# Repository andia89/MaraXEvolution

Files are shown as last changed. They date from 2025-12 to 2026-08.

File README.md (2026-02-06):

# MaraX Evolution - Main Controller




### Screenshot
[](https://github.com/user-attachments/assets/aa3f5071-2165-40e5-ae51-54051c40426c)

### Videos
| [](https://github.com/user-attachments/assets/e88c7372-fec7-41ba-ae10-4c3a202e55e9) | [](https://github.com/user-attachments/assets/11aead3c-08d9-41a0-b3eb-2458ce605d03) |
|:--:| :--:|
| *Pressure profiling with a blind flange. The pressure follows a complicated profile* | *Real shot with the custom Controller. The profile is set to produce a flat 9bar shot that stops at 40g (since the valve is not closed by the lever there will always be some additional coffee coming out after the pump stopped). As one can see the pressure neatly follows the 9bar (at one point I adjusted with the flow control paddle so that is when the pressure dropped). The grind was way to fine for this shot :D* |

This repository contains the hardware design and firmware for the **MaraX Evolution** main controller board. This project is designed to replace the stock controller of the Lelit Mara X espresso machine, adding advanced features such as PID temperature control, pressure profiling, weighing scale integration, and WiFi connectivity.

## Features

### Core Control
* **Hybrid Thermal Control:** Utilizes a custom **Feed-Forward + PID algorithm** (`feedForwardHeater`) that estimates heat loss based on ambient vs. boiler temperature, offering better stability than standard PIDs.
* **Dual-PID Architecture:** Dedicated PID loops for Temperature (Boiler/HX) and Pump (Pressure/Flow).
* **Smart State Machine:** Manages states including `COOLING_FLUSH`, `STEAM_BOOST`, and `STANDBY`.
* Performs all tasks the original Lelit MaraX machine does as well (boiler refill, water tank presence detection, relay activations etc...)

### Profiling & Extraction
* **Pressure Profiling:** Real-time pump dimmer control via Zero-Cross detection.
* **Flow Profiling:** (Requires [MaraX Evolution Scale](https://github.com/andia89/MaraXEvolution-Scale/)) Target specific flow rates (g/s) using Kalman-filtered weight data.
* **Gravimetric stopping:** (Requires [MaraX Evolution Scale](https://github.com/andia89/MaraXEvolution-Scale/)) Stop the shot after a set amount of time or when a certain weight is reached
* **Advanced Profiles:** Supports manual control, flat 9-bar shots, or complex JSON-based profiles (Ramped or Stepped).

### Integration & Connectivity
* **WiFi & MQTT:** Full smart home integration. Reports sensors (`boiler_temp`, `pressure`, `weight`) and accepts commands remotely.
* **Telnet CLI:** Built-in command-line interface for debugging and calibration over WiFi.
* **ESP-NOW HMI:** Low-latency connection to the optional [MaraX Evolution HMI](https://github.com/andia89/maraxevolution-hmi).
* **OTA Updates:** Update firmware wirelessly without opening the machine.

### Maintenance
* **Automated Cleaning:** Built-in backflush program (`CLEANING_START` -> `CLEANING_PUMPING` -> `PAUSE`).
* **Scale Calibration:** Integrated wizard for taring and calibrating the load cell.

## Repository Structure

* `controller_board/`: KiCad v6 hardware design files (schematics, PCB layout, and fabrication files).
* `firmware/`: PlatformIO project source code for the ESP32-based controller.

## Hardware Assembly

1.  **PCB Fabrication:** Use the Gerber and Drill files provided in `controller_board/jlcpcb/production_files/` to order the PCB.
2.  **Assembly:** Solder the components according to the BOM (`BOM-controller_board.csv`). The board features an Arduino-Nano ESP32 compatible footprint. See [Assembly](ASSEMBLY.md) for details
3.  **Installation:** Replace the existing Mara X controller with this board, ensuring all connections (sensors, pump, heating element) are mapped correctly.

## Firmware Compilation

The firmware is modular. You can enable/disable hardware features via `platformio.ini` build flags:

```cpp
build_flags = 
    -D HAS_PRESSURE_GAUGE
    -D HAS_SCALE
    -D HAS_SCREEN
```

The firmware is built using **PlatformIO**.

1.  Install [VSCode](https://code.visualstudio.com/) and the [PlatformIO extension](https://platformio.org/).
2.  Clone this repository.
3.  Open the `firmware` folder in PlatformIO.
4.  Configure `platformio.ini` if necessary (e.g., to select specific build environments or upload ports)
5.  Click the **Build** icon (checkmark) to compile.
6.  Connect your Arduino Nano ESP32 board via USB and click **Upload** (select `env:firmware` build environment).
7.  For subsequent uploads OTA should be enabled (you might have to adjust IP-address in `platformio.ini`) and selecting the `env:firmware-ota` environment

## [User Guide](USERGUIDE.md)

## [Parts list](PARTS.md)

## [Assembly instructions](ASSEMBLY.md)

## Support me

I had way too much fun building the MaraX Evolution—it turned into quite the obsession! I am definitely planning to tackle another coffee machine and give it the same "Evolution" treatment.

**However, espresso machines are expensive! :D**

If you enjoy this project or use it daily, please consider supporting me.

**Your Support = Your Vote**

When you support me on Ko-fi or Patreon, **please leave a comment telling me which coffee machine you want me to do next.**

Think of it as a voting system: As soon as I have enough funds to cover the machine with the most votes (and the parts to mod it), I will buy it, reverse-engineer it, and build an open-source controller for it. If you have the MaraX and still want to support me, you can also tell me if there is a specific feature you want to have!

I will keep track of the money earned and will update occasionally the votes on the different coffee machines that are requested

## Limitations
* The MaraX is a very good heatexchanger machine, using quite sophisticated hardware to achieve superior temperature stability than a lot of other HX machines out of the box. It is, however, not a dual boiler machine and as such perfect temperature control is almost impossible. I played around a lot with PID values and was able to come up with some good values (and some pretty sophisticated feed forward control), but still perfect stability is almost impossible (or only if one tunes the PID super conservative, but then it takes hours to heat the machine)
* This is not a cheap project. Most parts can be sourced pretty cheaply, but I used good ADC chips (the ADS1115) and one unfortunately obsolete LM1830 chip for boiler water level detection as well as a pretty expensive power supply for the 12V power. Most of these things could certainly be done cheaper (and maybe someday will). All in all expect to spend a bit of money if you go for the full set (which is recommended).
* In the end the softweare got waaaaay more complicated than I originally anticipated. Some software was written using AI but I went through all of it and made sure it made sense to me. There certainly will be bugs as there is an infinite amount of edge cases I certainly have not considered. Please report any bugs you may find

## Disclaimer & Safety Warning

**PLEASE READ CAREFULLY BEFORE PROCEEDING.**

**1. I am a Hobbyist, Not a Professional**
I am **not** a professional mechanical, electrical, or software engineer. This project was created purely as a personal hobby undertaking for educational purposes. The code and hardware designs provided here are **not** certified, tested to industrial standards, or guaranteed to be bug-free.

**2. Warranty Voiding**
Modifying your espresso machine, uploading custom firmware, or opening the chassis **will almost certainly void your manufacturer’s warranty**. By proceeding with any instructions or files from this repository, you accept full responsibility for the loss of any existing warranty or support from the original manufacturer.

**3. No Liability**
This software and hardware documentation is provided **"AS IS", WITHOUT WARRANTY OF ANY KIND**, express or implied.
* **I am not responsible** for any damage to your machine (bricking the device, burning out components, leaks, etc.).
* **I am not responsible** for any personal injury or property damage (including fire or electrical shock) resulting from the use of this project.
* **You assume all risk** associated with modifying your hardware and running this software.

**4. High Voltage & Pressure Warning**
Espresso machines involve **Mains Electricity (110V/220V)**, **Water**, and **High Pressure**. This is a dangerous combination.
* Never work on the machine while it is plugged in.
* Ensure you have a proper understanding of electrical safety before attempting any hardware modifications.
* Improper handling of the boiler or pressure lines can result in explosion or severe burns.

**Use this project entirely at your own risk.**

If you find anything that you think could be improved (be it software/electrical or mechanical side) please let me know, and feel free to open a Pull request

## Licensing
This project is dual-licensed to protect the work while allowing for personal study and modification.

* **Firmware:** The main source code located in the `/firmware` directory is licensed under the **PolyForm Noncommercial License 1.0.0**. You may modify and use it for personal projects, but you cannot use it for commercial products.
    * *Third-Party Libraries:* This firmware includes modified versions of the following libraries, which remain under their original licenses:
        * [dimmable-light](https://github.com/fabianoriccardi/dimmable-light): Licensed under **LGPL-2.1**.
        * [PID_v1](https://github.com/br3ttb/Arduino-PID-Library/tree/master): Licensed under **MIT License**.
        * [Simple Kalman Filter](https://github.com/denyssene/SimpleKalmanFilter): Licensed under **MIT License**.

* **Firmware:** The hardware designs, schematics, and 3D models located in the /controller_board and /hv_board directories are licensed under the Creative Commons Attribution-NonCommercial 4.0 International (CC BY-NC 4.0) license.

Please see the LICENSE file in each respective subdirectory for the full legal text.

## Similar projects
Idea for controlling the pump via an AC dimmer has been done in https://github.com/larszi/marax-pressure-mod. A complete overhaul of control software is currently proposed by the great project in https://github.com/variegated-coffee (they try to make a one-fit all solution though)

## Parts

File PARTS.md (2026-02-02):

## Parts List

 * PCBs for both the controller board and the HV board. I had good experience with JLCPCB but PCBWay is also fine. The gerber files can be found in production_files in the jlcpcb folder. 

* Electronic parts for assembly. They are listed at the end of this section in [Controller board](#conroller-board) and [HV board](#hv-board)

* If you want to use a pressure transducer (this is necessary to do profiling based on pressure, and to electronically monitor the pressure). 
    * The board is designed for [this one](https://aliexpress.com/item/4000756631924.html?spm=a2g0o.order_list.order_list_main.5.ee9e1802cAHCQO); specifically 0-1.6MPa at 0.5V-4.5V and a supply voltage of 12V
    * [T-Piece for pipe](https://www.landefeld.de/artikel/de/t-steckanschluss-5mm-5mm-iqs-msv-standard-/IQST%2050%20MSV). It is important to note that the MaraX uses 5mm pipes which are quite non-standard
    * [Pipe push fitting](https://www.landefeld.de/artikel/de/steckanschluss-m-innengew-m-5-4mm-iqs-msv-standard-/IQSF%20M54%20MSV)
    * [5mm polyurethane pipe](https://www.landefeld.de/artikel/de/polyurethan-schlauch-5-x-3-mm-blau-meterware-von-50-mtr-rolle-/PU%205X3%20BLAU); get 1m to have a bit left-over
    * [Molex connector](https://www.mouser.at/ProductDetail/Molex/50-57-9403?qs=u6Gr9%2FNt%252B%2F9Ok3bHhq8UPA%3D%3D) that has its mate on the controller board, with at least [3 Receptables that need to be crimped on the wire](https://www.mouser.at/ProductDetail/Molex/16-02-0102?qs=UAyrm%2FnZ%252BCifWkt7bqgfPw%3D%3D)
* If you want to use AC dimmer for flow/pressure profiling (and you either have the Pressure transducer and/or the scale installed) one additional (ideally heat-resistant cable) is necessary. Two [Connectors](https://www.mouser.at/ProductDetail/571-606501) like this one have to be crimped on a sufficiently long cable. 

### Controller Board

The BOM for the controller board is divided into **SMD components** (suitable for JLCPCB's SMT service) and **Handsolder components** (precision parts, connectors, and the microcontroller to be sourced from Mouser/DigiKey).

#### 1. SMD Components (JLCPCB SMT Service)
These components have LCSC part numbers included in the BOM and can be assembled by the JLCPCB SMT service. Alternatively they can be of course hand soldered. These Resistors and Capacitors are mainly used for Pull-up/down, current limiting and filtering, as such their exact values are not that important. The transistors are mainly used for switching LEDs. In both controller_board and hv_board folder there is a jlcpcb folder that contains all the necessary files for fabrication as well as SMT assembly.

| Comment | Designator | Footprint | LCSC Part | Qty |
| :--- | :--- | :--- | :--- | :--- |
| **0** | R15 | R 0805 | [C17477](https://lcsc.com/product-detail/C17477.html) | 1 |
| **0.05uF** | C6 | C 0805 | [C53134](https://lcsc.com/product-detail/C53134.html) | 1 |
| **0.22u** | C3 | C 0805 | [C5378](https://lcsc.com/product-detail/C5378.html) | 1 |
| **100nF** | C7, C8, C9, C11 | C 0805 | [C28233](https://lcsc.com/product-detail/C28233.html) | 4 |
| **1nF** | C4 | C 0805 | [C46653](https://lcsc.com/product-detail/C46653.html) | 1 |
| **1uF** | C1, C2, C5, C10 | C 0805 | [C28323](https://lcsc.com/product-detail/C28323.html) | 4 |
| **10K** | R1, R3, R5, R7, R9, R10, **R13**, R18, R20, R22, R24, R28, R30, R31, R32, R33, R35, R38 | R 0805 | [C17414](https://lcsc.com/product-detail/C17414.html) | 18 |
| **20uF** | C13 | C 0805 | [C45783](https://lcsc.com/product-detail/C45783.html) | 1 |
| **47uF** | C12 | C 0805 | [C28323](https://lcsc.com/product-detail/C28323.html) | 1 |
| **220** | R23, R25, R26, R34, R36, R39 | R 0805 | [C17557](https://lcsc.com/product-detail/C17557.html) | 6 |
| **300** | R8 | R 0805 | [C17617](https://lcsc.com/product-detail/C17617.html) | 1 |
| **30K** | R17, R19, R21 | R 0805 | [C17621](https://lcsc.com/product-detail/C17621.html) | 3 |
| **470** | R14, R27, R37, R40 | R 0805 | [C17710](https://lcsc.com/product-detail/C17710.html) | 4 |
| **47K** | R6, R29 | R 0805 | [C17713](https://lcsc.com/product-detail/C17713.html) | 2 |
| **BSS138** | Q1, Q2, Q3, Q4, Q5, Q6 | SOT-23 | [C15277](https://lcsc.com/product-detail/C15277.html) | 6 |

#### 2. Handsolder Components (Mouser / DigiKey)
These parts are not included in the SMT assembly and must be purchased separately.

**Precision Resistors**
*0.1% tolerance is recommended for these voltage dividers. If this is really necessary I am not sure, but I used 0.1% tolerance ones and it works great*

| Value | Designator | Qty | Link (Mouser) |
| :--- | :--- | :--- | :--- |
| **1K5** | R12 | 1 | [0805 1.5K 0.1%](https://www.mouser.com/c/?q=0805%20resistor%201.5kOhms%200.1%25) |
| **5K6** | R11 | 1 | [0805 5.6K 0.1%](https://www.mouser.com/c/?q=0805%20resistor%205.6kOhms%200.1%25) |
| **10K** | R2, R4 | 2 | [0805 10K 0.1%](https://www.mouser.com/c/?q=0805%20resistor%2010kOhms%200.1%25) |
| **-** | **R16** | **0** | **DNP (Do Not Populate)** |

**ICs & Modules**

| Part Name | Designator | Description | Qty | Link (Mouser) | Comment | 
| :--- | :--- | :--- | :--- | :--- | :--- |
| **Arduino Nano ESP32**| A1 | Microcontroller | 1 | [Arduino Nano ESP32](https://www.mouser.com/c/?q=Arduino%20Nano%20ESP32) | with headers if directly soldered to the board. Otherwise [Mill-Max](https://www.mill-max.com/products/new/precision-machined-pin-headers) headers are a way to socket it (there is not enough vertical space for standard machine headers)
| **ADS1115IDGS** | U1 | 16-Bit ADC | 1 | [ADS1115IDGS](https://www.mouser.com/c/?q=ADS1115IDGS) | Any ADS1115 will work fine
| **AQV212** | IC1 | PhotoMOS Relay | 1 | [AQV212](https://www.mouser.com/c/?q=AQV212%20DIP-6) | can be socketed using standard DIP-6 socket
| **IE092503-1** | U3 | Buzzer | 1 | [IE092503-1](https://www.mouser.com/c/?q=IE092503-1) | If you don't want a buzzer, can be omitted
| **LM4050AEM3-3.0** | IC2 | Voltage Reference 3.0V | 1 | [LM4050AEM3-3.0](https://www.mouser.com/c/?q=LM4050AEM3-3.0) | A precise voltage reference for temperature measurements

**Connectors**

| Part Name | Designator | Description | Qty | Link (Mouser) | Comment | 
| :--- | :--- | :--- | :--- | :--- | :--- |
| **280377-2** | CN1, CN2, CN3, CN4, CN5, CN7 | TE Ampmodu II (2 pos) | 6 | [TE 280377-2](https://www.mouser.com/c/?q=280377-2) |
| **280389-2** | CN6 | TE Ampmodu II (8 pos) | 1 | [TE 280389-2](https://www.mouser.com/c/?q=280389-2) |
| **70553-0002** | J4 | Molex SL Header (3 pos)| 1 | [Molex 70553-0002](https://www.mouser.com/c/?q=705530002) | Can be omitted if no pressure transducer is to be installed
| **70553-0041** | J5 | Molex SL Header (7 pos) | 1 | [Molex 70553-0041](https://www.mouser.com/c/?q=705530041) | Can be omitted if no scale is to be installed
| **MTMM-106-14-T-S-520** | J2 | 2.00mm Pitch Header | 1 | [Header 1x06 2mm](https://www.mouser.com/c/?q=MTMM-106-14-T-S-520) | This mates with the correspnding ESQT connector on the HV board. The exact part numbers are not that important, but the two connectors need to bridge a gap of 27mm (distance between the topsides of both PCBs)

#### 3. Special Components
This component is obsolete and typically requires sourcing from eBay.

| Component | Designator | Note | Link | Comment |
| :--- | :--- | :--- | :--- | :--- |
| **LM1830N** | U2 | Fluid Level Detector | [Search on eBay](https://www.ebay.com/sch/i.html?_nkw=LM1830N) | Can be socketed by using socket for N14A package

### HV Board

These components have LCSC part numbers included in the BOM and can be assembled by the JLCPCB SMT service. Alternatively they can be of course hand soldered. These Resistors and Capacitors are mainly used for Pull-up/down, current limiting and filtering, as such their exact values are not that important. Transistors are used to switch the Relays and Diodes as flyback. Both can be cheaply done with SMT service from JLCPCB

#### 1. SMD Components (JLCPCB SMT Service)
These components have LCSC part numbers and can be assembled by the JLCPCB SMT service.

| Comment | Designator | Footprint | LCSC Part | Qty |
| :--- | :--- | :--- | :--- | :--- |
| **100** | R8 | R 0805 | [C17408](https://lcsc.com/product-detail/C17408.html) | 1 |
| **10K** | R1, R28 | R 0805 | [C17414](https://lcsc.com/product-detail/C17414.html) | 2 |
| **1k** | R7 | R 0805 | [C17513](https://lcsc.com/product-detail/C17513.html) | 1 |
| **BAT46WJ** <br>*(I would have liked the BAT46WJ but only the BAT46WS is available for SMT service. It is also fine)* | U3, U4 | SC-90 / SOD323F | [C7502692](https://lcsc.com/product-detail/C7502692.html) | 2 |
| **BSS138** | Q1, Q2 | SOT-23 | [C7420339](https://lcsc.com/product-detail/C7420339.html) | 2 |

#### 2. Handsolder Components (Mouser / DigiKey)
These parts involve mains voltage or high power.

**High Power Resistors (2010 Package)**
*Note: These require the larger 2010 [5025 metric] footprint for power handling. Go for Power rating of >1W for those*

| Value | Designator | Qty | Link (Mouser) | Comments |
| :--- | :--- | :--- | :--- | :--- |
| **47k** | R5, R6 | 2 | [2010 Resistor 47k](https://www.mouser.com/c/?q=2010%20resistor%2047k) | Use at least 1W rating. Can be omitted if AC dimmer is not used
| **330** | R9 | 1 | [2010 Resistor 330](https://www.mouser.com/c/?q=2010%20resistor%20330) | Use at least 1W rating. Can be omitted if AC dimmer is not used
| **39** | R11 | 1 | [2010 Resistor 39](https://www.mouser.com/c/?q=2010%20resistor%2039) | Use at least 1W rating. Can be omitted if AC dimmer is not used

**Relays, Triacs & Power Modules**

| Part Name | Designator | Description | Qty | Link (Mouser) | Comment |
| :--- | :--- | :--- | :--- | :--- | :--- |
| **ECE10US12** | U1 | AC-DC Converter 12V | 1 | [ECE10US12](https://www.mouser.com/c/?q=ECE10US12) |
| **ALDP112** | U2 | Panasonic Relay 12V | 1 | [ALDP112](https://www.mouser.com/c/?q=ALDP112) |
| **RT314A12** | K1 | TE Schrack Relay 12V | 1 | [RT314A12](https://www.mouser.com/c/?q=RT314A12) |
| **BTA16-600BWRG**| Q3 | Triac 600V 16A | 1 | [BTA16-600BWRG](https://www.mouser.com/c/?q=BTA16-600BWRG) | Can be omitted if AC dimmer is not used
| **H11L1** | U5 | Optocoupler (Logic) | 1 | [H11L1](https://www.mouser.com/c/?q=H11L1) | Can be omitted if AC dimmer is not used. Can be socketed with DIP-6 socket
| **MOC3021M** | U7 | Optocoupler (Triac) | 1 | [MOC3021M](https://www.mouser.com/c/?q=MOC3021M) | Can be omitted if AC dimmer is not used. Can be socketed with DIP-6 socket
| **W04G** | D1 | Bridge Rectifier | 1 | [W04G](https://www.mouser.com/c/?q=W04G) | Can be omitted if AC dimmer is not used
| **7178DG** | H1 | Heatsink for Triac | 1 | [7178DG](https://www.mouser.com/c/?q=7178DG) | Can be omitted if AC dimmer is not used

**Capacitors & Fuses**

| Part Name | Designator | Description | Qty | Link (Mouser) | Comment |
| :--- | :--- | :--- | :--- | :--- | :--- |
| **VJ2220Y103K...**| C1 | 2220 Safety Cap X2 | 1 | [VJ2220Y103KXUSTX2](https://www.mouser.com/c/?q=VJ2220Y103KXUSTX2) | Can be omitted if AC dimmer is not used
| **100uF** | C3 | Radial (D6.3mm P2.5mm) | 1 | [100uF Radial 6.3mm 2.5mm](https://www.mouser.com/c/?q=100uF%20radial%206.3mm%202.5mm%20pitch) |
| **0034.6808** | F1 | Schurter MSS Fuse | 1 | [0034.6808](https://www.mouser.com/c/?q=0034.6808) |
| **0697H9100-02** | F2 | Bel Fuse Radial | 1 | [0697H9100-02](https://www.mouser.com/c/?q=0697H9100-02) |
| **3413.0215.22** | F4 | Schurter SMD Fuse | 1 | [3413.0215.22](https://www.mouser.com/c/?q=3413.0215.22) |

**Connectors**

| Name | Designator | Description | Qty | Link |
| :--- | :--- | :--- | :--- | :--- |
| **571-160650-2** | FA1, FA4, FA7, FA10, FA11 | Faston Tabs 6.35mm | 5 | [571-160650-2](https://www.mouser.at/ProductDetail/571-160650-2) |
| **ESQT-106-02-L-S-530** | J6 | 2.00mm Pitch Female Header Receptable | 1 | [Socket 1x06 2mm](https://www.mouser.com/c/?q=ESQT-106-02-L-S-530) | This mates with the corresponding MTMM connector on the controller board. The exact part numbers are not that important, but the two connectors need to bridge a gap of 27mm (distance between the topsides of both PCBs)

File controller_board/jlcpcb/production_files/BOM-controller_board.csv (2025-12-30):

Comment | Designator | Footprint | LCSC | Quantity
0 | R15 | R_0805_2012Metric_Pad1.20x1.40mm_HandSolder | C17477 | 1
0.05uF | C6 | C_0805_2012Metric_Pad1.18x1.45mm_HandSolder | C53134 | 1
0.22u | C3 | C_0805_2012Metric_Pad1.18x1.45mm_HandSolder | C5378 | 1
100nF | C11,C7,C8,C9 | C_0805_2012Metric_Pad1.18x1.45mm_HandSolder | C28233 | 4
10K | R1,R10,R13,R18,R20,R22,R24,R28,R3,R30,R31,R32,R33,R35,R38,R5,R7,R9 | R_0805_2012Metric_Pad1.20x1.40mm_HandSolder | C17414 | 18
1nF | C4 | C_0805_2012Metric_Pad1.18x1.45mm_HandSolder | C46653 | 1
1uF | C1,C10,C2,C5 | C_0805_2012Metric_Pad1.18x1.45mm_HandSolder | C28323 | 4
20uF | C13 | C_0805_2012Metric_Pad1.18x1.45mm_HandSolder | C45783 | 1
220 | R23,R25,R26,R34,R36,R39 | R_0805_2012Metric_Pad1.20x1.40mm_HandSolder | C17557 | 6
300 | R8 | R_0805_2012Metric_Pad1.20x1.40mm_HandSolder | C17617 | 1
30K | R17,R19,R21 | R_0805_2012Metric_Pad1.20x1.40mm_HandSolder | C17621 | 3
470 | R14,R27,R37,R40 | R_0805_2012Metric_Pad1.20x1.40mm_HandSolder | C17710 | 4
47K | R29,R6 | R_0805_2012Metric_Pad1.20x1.40mm_HandSolder | C17713 | 2
47uF | C12 | C_0805_2012Metric_Pad1.18x1.45mm_HandSolder | C16780 | 1
BSS138 | Q1,Q2,Q3,Q4 | SOT-23 | C7420339 | 4
5K6 | R11 | R_0805_2012Metric_Pad1.20x1.40mm_HandSolder |  | 1
Heater SSR Relay | CN5 | 280377-2_TYC |  | 1
1K5 | R12 | R_0805_2012Metric_Pad1.20x1.40mm_HandSolder |  | 1
LM1830N | U2 | PDIP14_19P56X6P35_ONS |  | 1
705530041 | J5 | CONN_70553-xxxx_07_MOL |  | 1
MISC LEDS | CN6 | 280389-2_TYC |  | 1
HV Board | J2 | PinHeader_1x06_P2.00mm_Vertical |  | 1
Brew switch | CN7 | 280377-2_TYC |  | 1
AQV212 | IC1 | DIP762W47P254L880H410Q6N |  | 1
IE092503-1 | U3 | IE0925031 |  | 1
Sensor brew boiler | CN4 | 280377-2_TYC |  | 1
10K | R2 | R_0805_2012Metric_Pad1.20x1.40mm_HandSolder |  | 1
705530002 | J4 | CONN_705530002_03_MOL |  | 1
LM4050AEM3-3.0+T | IC2 | SOT95P237X112-3N |  | 1
1-100k | R16 | R_0805_2012Metric_Pad1.20x1.40mm_HandSolder |  | 1
Water level detector | CN2 | 280377-2_TYC |  | 1
ADS1115IDGS | U1 | VSSOP-10_3x3mm_P0.5mm |  | 1
Boiler fill sensor | CN1 | 280377-2_TYC |  | 1
10K | R4 | R_0805_2012Metric_Pad1.20x1.40mm_HandSolder |  | 1
Arduino_Nano_ESP32 | A1 | Arduino_Nano |  | 1
Sensor steam boiler | CN3 | 280377-2_TYC |  | 1

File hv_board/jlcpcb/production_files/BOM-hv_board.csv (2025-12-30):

Comment | Designator | Footprint | LCSC | Quantity
100 | R8 | R_0805_2012Metric_Pad1.20x1.40mm_HandSolder | C17408 | 1
10K | R1,R28 | R_0805_2012Metric_Pad1.20x1.40mm_HandSolder | C17414 | 2
1k | R7 | R_0805_2012Metric_Pad1.20x1.40mm_HandSolder | C17513 | 1
BAT46WJ_115 | U3,U4 | SC-90_SOD323F_NEX | C7502692 | 2
BSS138 | Q1,Q2 | SOT-23 | C7420339 | 2
ALDP112 | U2 | PAN_ALD_PAN |  | 1
H11L1 | U5 | H11L1_ISO |  | 1
47k | R6 | R_2010_5025Metric_Pad1.40x2.65mm_HandSolder |  | 1
0034.6808 | F1 | FUS_SCHURTER_0034_SCH |  | 1
W04G | D1 | Diode_Bridge_Round_D9.8mm |  | 1
47k | R5 | R_2010_5025Metric_Pad1.40x2.65mm_HandSolder |  | 1
7178DG | H1 | 7178DG |  | 1
MOC3021M | U7 | PDIP6_BX_ONS |  | 1
230 Live | FA1 | 1606502 |  | 1
VJ2220Y103KXUSTX2 | C1 | CAPC5651X218N |  | 1
Pump Relay | FA11 | 1606502 |  | 1
39 | R11 | R_2010_5025Metric_Pad1.40x2.65mm_HandSolder |  | 1
RT314A12 | K1 | Relay_SPDT_Schrack-RT1-16A-FormC_RM5mm |  | 1
3413.0215.22 | F4 | FUS1206_24N_SCH |  | 1
230 Neutral | FA4 | 1606502 |  | 1
BTA16-600BWRG | Q3 | TO255P460X1020X2005-3P |  | 1
PumpOut | FA10 | 1606502 |  | 1
100uF | C3 | CP_Radial_D6.3mm_P2.50mm |  | 1
330 | R9 | R_2010_5025Metric_Pad1.40x2.65mm_HandSolder |  | 1
Coffee Relay | FA7 | 1606502 |  | 1
ECE10US12 | U1 | RELAY4_ECE10_XPR |  | 1
0697H9100-02 | F2 | 0697_BEL |  | 1
Controller board | J6 | PinHeader_1x06_P2.00mm_Vertical |  | 1

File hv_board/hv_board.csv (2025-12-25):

ID | Bezeichner | Footprint | Stückzahl | Bezeichnung | Anbieter und Referenz
1 | U2 | PAN_ALD_PAN | 1 | ALDP112
2 | U5 | H11L1_ISO | 1 | H11L1
3 | R6,R5 | R_2010_5025Metric_Pad1.40x2.65mm_HandSolder | 2 | 47k
4 | F1 | FUS_SCHURTER_0034_SCH | 1 | 0034.6808
5 | D1 | Diode_Bridge_Round_D9.8mm | 1 | W04G
6 | R1,R28 | R_0805_2012Metric_Pad1.20x1.40mm_HandSolder | 2 | 10K
7 | H1 | 7178DG | 1 | 7178DG
8 | U7 | PDIP6_BX_ONS | 1 | MOC3021M
9 | FA1 | 1606502 | 1 | 230 Live
10 | FA11 | 1606502 | 1 | Pump Relay
11 | U3,U4 | SC-90_SOD323F_NEX | 2 | BAT46WJ_115
12 | R11 | R_2010_5025Metric_Pad1.40x2.65mm_HandSolder | 1 | 39
13 | K1 | Relay_SPDT_Schrack-RT1-16A-FormC_RM5mm | 1 | RT314A12
14 | R7 | R_0805_2012Metric_Pad1.20x1.40mm_HandSolder | 1 | 1k
15 | Q1,Q2 | SOT-23 | 2 | BSS138
16 | F4 | FUS1206_24N_SCH | 1 | 3413.0215.22
17 | R8 | R_1206_3216Metric_Pad1.30x1.75mm_HandSolder | 1 | 86.6
18 | FA4 | 1606502 | 1 | 230 Neutral
19 | Q3 | TO255P460X1020X2005-3P | 1 | BTA16-600BWRG
20 | C2 | CAP_F339MX231031MDA2B0_VIS | 1 | F339MX231031MDA2B0
21 | FA10 | 1606502 | 1 | PumpOut
22 | C3 | CP_Radial_D6.3mm_P2.50mm | 1 | 100uF
23 | R9 | R_2010_5025Metric_Pad1.40x2.65mm_HandSolder | 1 | 330
24 | FA7 | 1606502 | 1 | Coffee Relay
25 | U1 | RELAY4_ECE10_XPR | 1 | ECE10US12
26 | F2 | 0697_BEL | 1 | 0697H9100-02
27 | J6 | PinHeader_1x06_P2.00mm_Vertical | 1 | Controller board

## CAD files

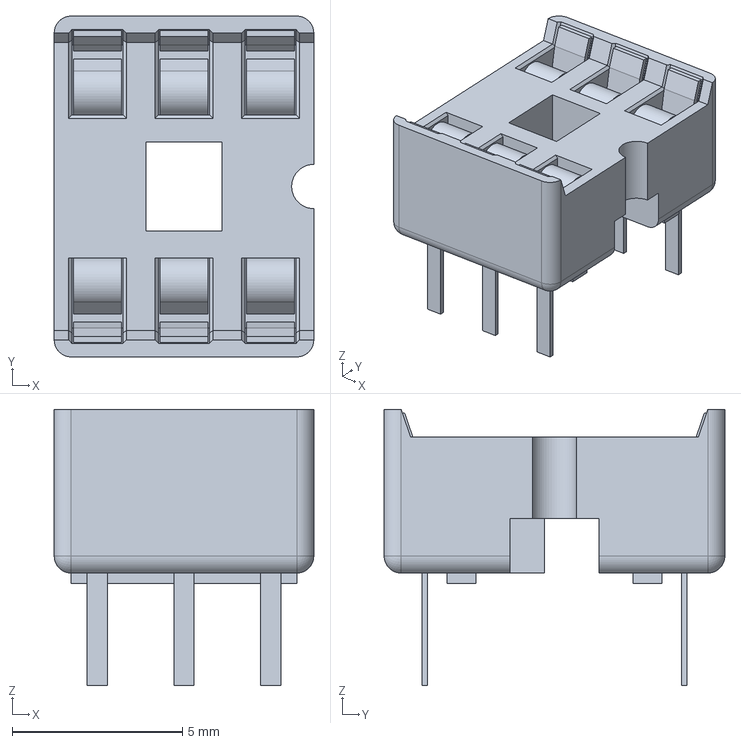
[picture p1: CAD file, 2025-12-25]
controller_board/LIB_1-2199298-1/1-2199298-1/3D/1-2199298-1.stp
7.62 x 10.0 x 8.10 mm

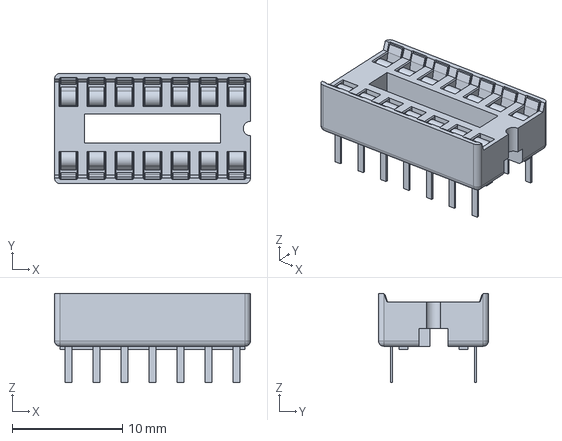
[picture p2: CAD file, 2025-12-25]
controller_board/LIB_1-2199298-3/1-2199298-3/3D/1-2199298-3.stp
17.8 x 10.0 x 8.10 mm

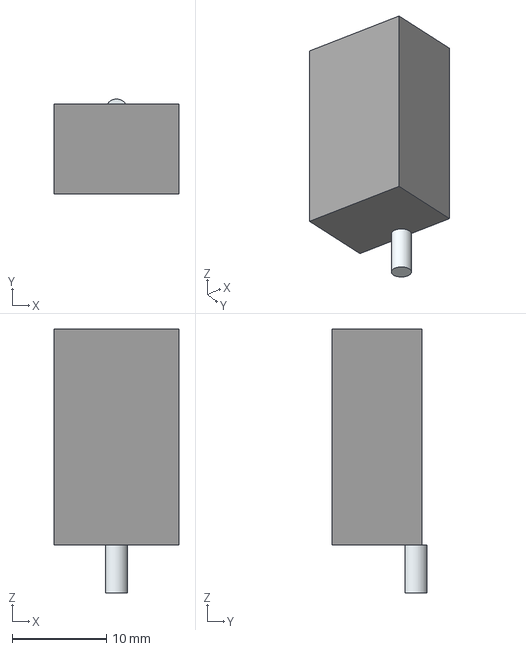
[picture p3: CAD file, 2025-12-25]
controller_board/LIB_7178DG/7178DG/3D/7178DG.stp
13.2 x 10.1 x 28.0 mm
Leads

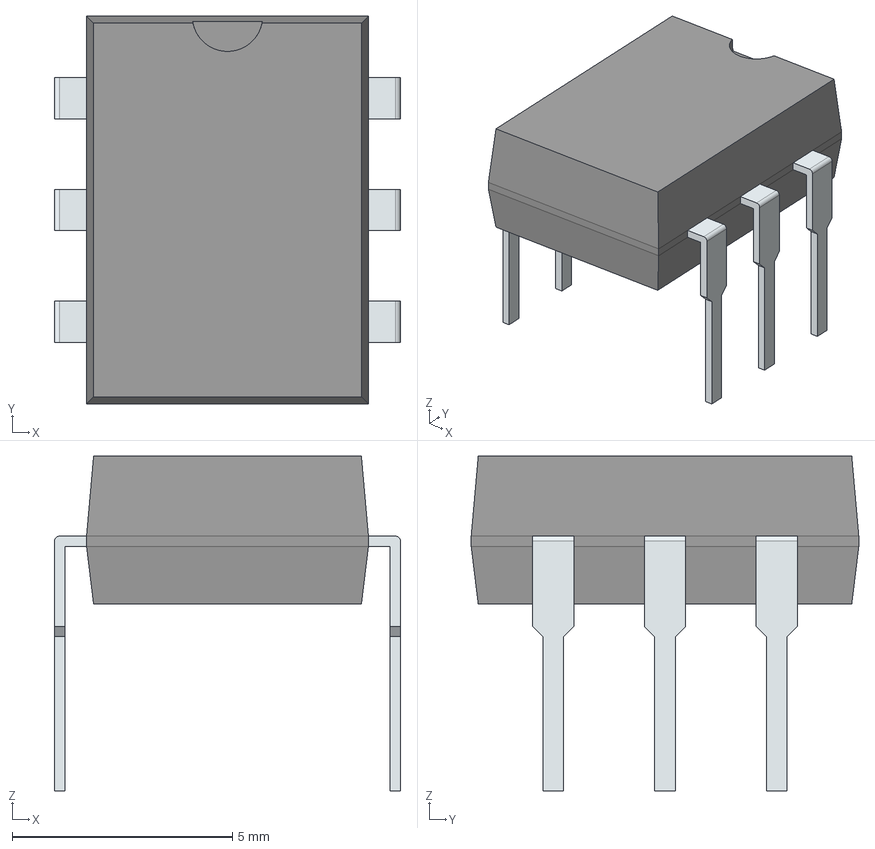
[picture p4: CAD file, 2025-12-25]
controller_board/LIB_AQV212/AQV212/3D/AQV212.stp
7.86 x 8.80 x 7.60 mm
PinsArrayLR

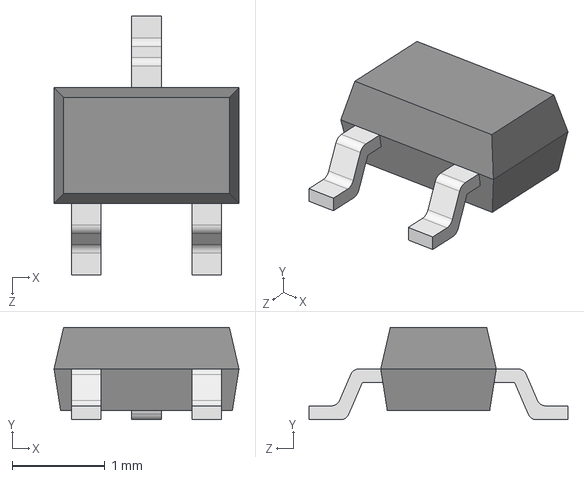
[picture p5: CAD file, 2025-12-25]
controller_board/LIB_LM4050AEM3-3.0+T/LM4050AEM3-3.0+T/3D/LM4050AEM3-3.0+T.stp
2.00 x 1.00 x 2.80 mm

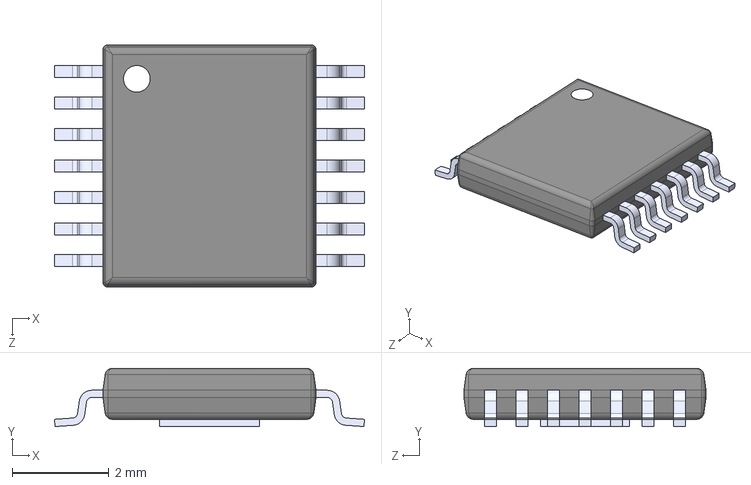
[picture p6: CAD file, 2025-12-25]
controller_board/LIB_TPS1HTC30AQPWPRQ1/TPS1HTC30AQPWPRQ1/3D/TPS1HTC30AQPWPRQ1.stp
6.40 x 1.20 x 5.00 mm

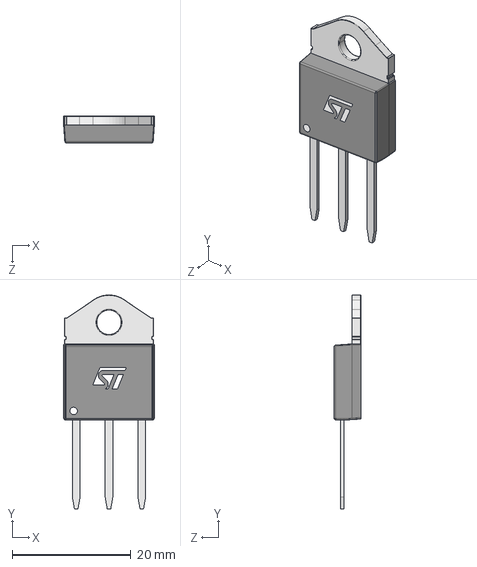
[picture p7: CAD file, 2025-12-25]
hv_board/LIB_BTA16-600BWRG/BTA16-600BWRG/3D/BTA16-600BWRG.stp
15.3 x 36.1 x 4.50 mm
T5035H-8PI
STMicro Logo

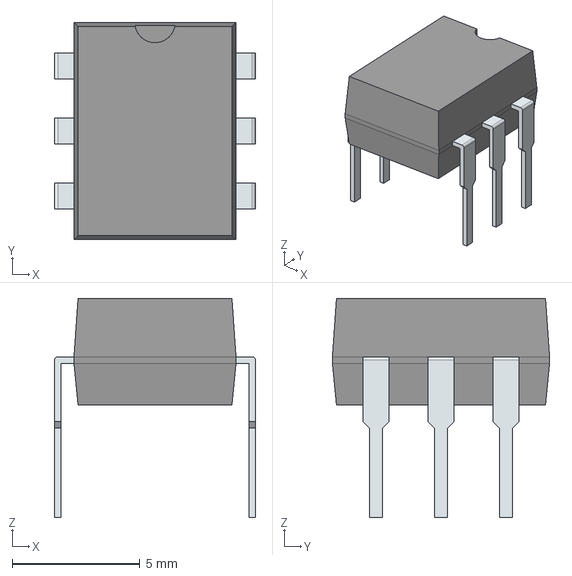
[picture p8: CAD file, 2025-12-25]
hv_board/LIB_H11L1M/H11L1M/3D/H11L1M.stp
7.88 x 8.51 x 8.58 mm
PinsArrayLR

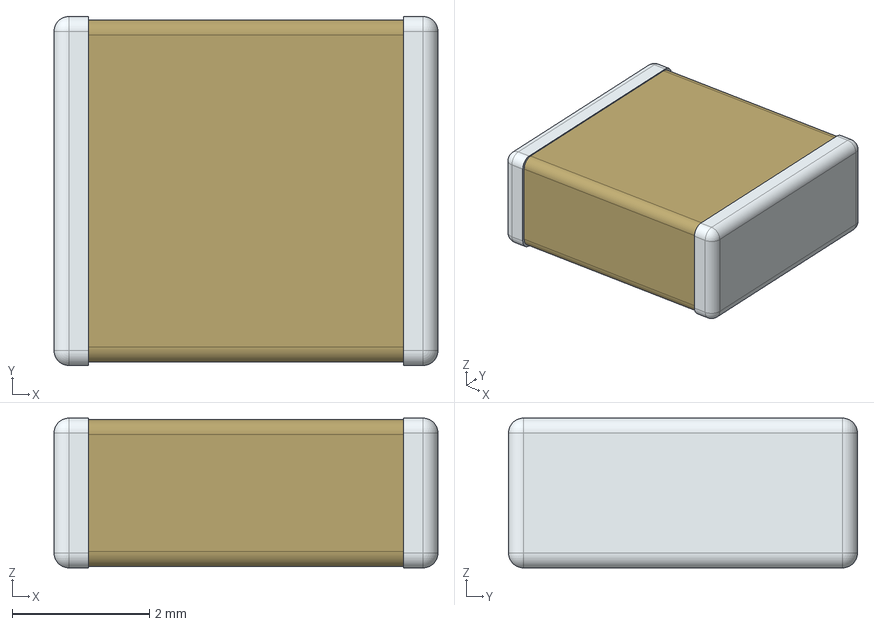
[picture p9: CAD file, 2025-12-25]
hv_board/LIB_VJ2220Y103KXUSTX2/VJ2220Y103KXUSTX2/3D/VJ2220Y103KXUSTX2.stp
5.59 x 5.08 x 2.18 mm

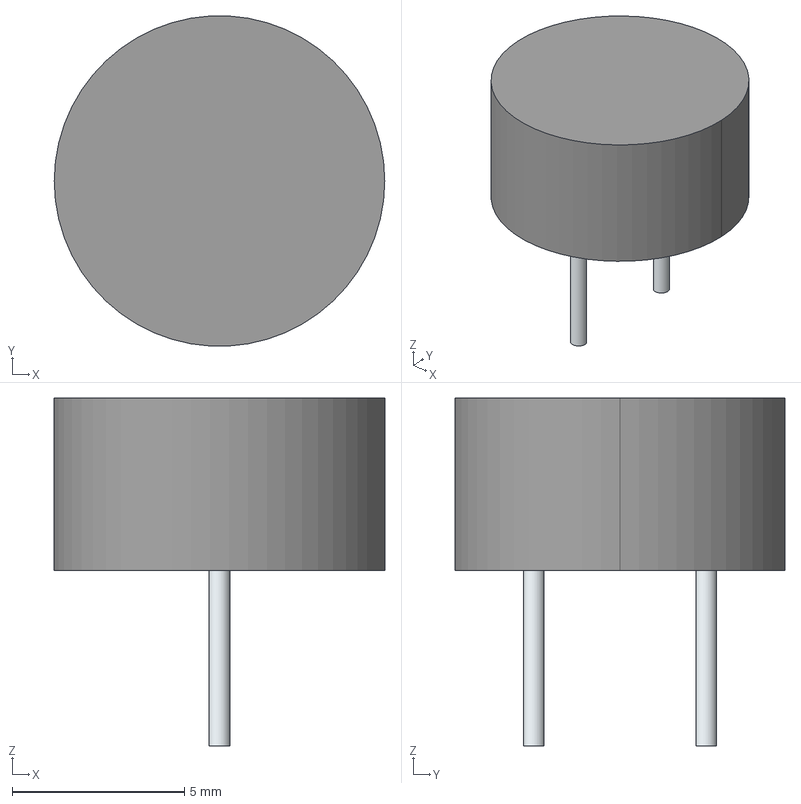
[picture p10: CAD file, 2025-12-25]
controller_board/LIB_IE092503-1/IE092503-1/3D/IE092503-1.stp
9.60 x 9.58 x 10.1 mm
Leads x 2

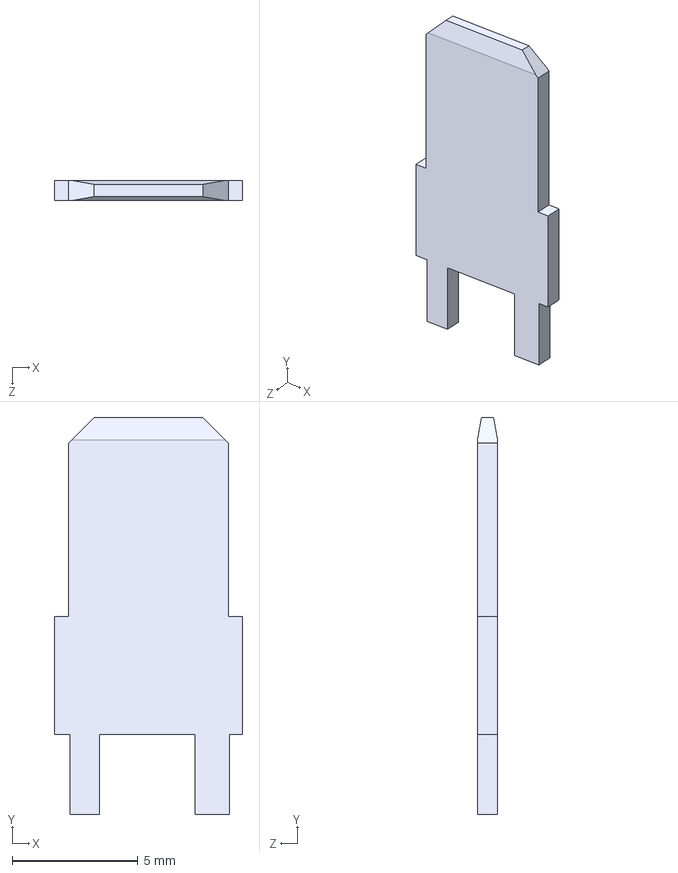
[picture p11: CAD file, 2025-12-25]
hv_board/624091/62409-1.step
7.49 x 15.8 x 0.8 mm

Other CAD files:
controller_board/LIB_1-2199298-1/1-2199298-1/Allegro/dips762w70p254l762h510q6n.psm
controller_board/LIB_1-2199298-1/1-2199298-1/DEHDL/1_2199298_1/chips/chips.prt
controller_board/LIB_1-2199298-3/1-2199298-3/Allegro/dips762w70p254l1778h510q14n.psm
controller_board/LIB_1-2199298-3/1-2199298-3/DEHDL/1_2199298_3/chips/chips.prt
controller_board/LIB_7178DG/7178DG/Allegro/7178dg.psm
controller_board/LIB_7178DG/7178DG/DEHDL/7178dg/chips/chips.prt
controller_board/LIB_AQV212/AQV212/Allegro/dip762w47p254l880h410q6n.psm
controller_board/LIB_AQV212/AQV212/DEHDL/aqv212/chips/chips.prt
controller_board/LIB_IE092503-1/IE092503-1/Allegro/ie0925031.psm
controller_board/LIB_IE092503-1/IE092503-1/DEHDL/ie092503_1/chips/chips.prt
controller_board/LIB_LM4050AEM3-3.0+T/LM4050AEM3-3.0+T/Allegro/sot95p237x112-3n.psm
controller_board/LIB_LM4050AEM3-3.0+T/LM4050AEM3-3.0+T/DEHDL/lm4050aem3_3.0_t/chips/chips.prt
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

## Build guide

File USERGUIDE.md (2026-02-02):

# MaraX Evolution - User Manual

This manual documents the operation, configuration, and API references for the custom ESP32 firmware designed for the Lelit MaraX V2 modification project.

## 1. Getting Started

### Initial Setup (WiFi)

1. On first boot, the machine creates a WiFi Access Point named **`MaraX-Setup`**.

2. Connect to this network with your phone or laptop.

3. A captive portal should open automatically (or visit `192.168.4.1`).

4. Enter your home WiFi credentials.

5. The machine will reboot and connect to your local network.

### Hardware Configuration

**Optional Hardware**
The system supports the following optional add-ons (strongly recommended to unlock the full potential):

* **[MaraXEvolution-Scale](https://github.com/andia89/MaraXEvolution-Scale)** For gravimetric dosing and flow profiling.

* **[MaraXEvolution-HMI](https://github.com/andia89/MaraXEvolution-HMI)** A dedicated display connected via ESP-NOW.

**Setting MQTT Credentials**
To enable remote monitoring, configure your broker details using one of the following methods:

* **Via Telnet:** Connect to Port 23 and use the `set` command.

  * Example: `set mqtt_server=192.168.1.10`

  * Example: `set mqtt_user=myUser`

  * Example: `set mqtt_password=myPassword`

* **Via HMI Screen:** Use the configuration portal on the MaraXEvolution-HMI.

## 2. Machine States & Feedback

The machine operates in a finite state machine. You can monitor the state via MQTT (`espresso/status/state`) or Telnet (`status`) or the accompanying HMI device. 

| State | Description | 
 | ----- | ----- | 
| **INIT** | System initialization (Sensors, WiFi). | 
| **HEATING** | Active heating to reach `tempsetbrew`. | 
| **IDLE** | Target temperature reached and stable. | 
| **BREWING** | Shot in progress (Pump active, Profiling active). | 
| **STEAM_BOOST** | Post-shot steam boost (active for 60s or until cancelled). | 
| **STANDBY** | Low power mode after 15 minutes of inactivity. | 
| **COOLING_FLUSH** | Automated flush to bring HX temperature down. | 
| **CLEANING** | Automated backflush cycle states. | 
| **WATER_EMPTY** | Tank empty detected. Pump/Heater disabled. | 
| **BOILER_EMPTY** | Steam boiler level low. Auto-fill active. | 
| **ERROR** | Critical sensor failure (NTC short/disconnect). Heater disabled. | 

## 3. Telnet Command Reference

Connect to the machine using a Telnet client (e.g., PuTTY) on **Port 23** of the machine's IP address.

### General Commands

| Command | Arguments | Description | 
 | ----- | ----- | ----- | 
| `help` |  | Lists available commands. | 
| `status` |  | Prints full system dashboard (Temps, PID, RSSI). | 
| `reboot` |  | Restarts the ESP32. | 
| `macaddress` |  | Prints the device WiFi MAC address. | 
| `lasterror` |  | Prints the last recorded critical error message. | 
| `flush` | `<ms>` | Runs the pump for X milliseconds (e.g., `flush 2000`). | 
| `debug` |  | Toggles **DEBUG** mode (Unlocks hardware control). | 
| `set` | `<key>=<val>` | Manually set a setting (see Settings Reference). | 

### Scale & Calibration

| Command | Arguments | Description | 
 | ----- | ----- | ----- | 
| `tare_scale` |  | Zeros the scale. | 
| `calibratescale` |   | Starts calibration wizard. Step 1: Tare. | 
| `calibratenext` | `<weight_g>` | Step 2: Place known weight (arg) and calculate factor. | 

### Debug Hardware (Requires DEBUG Mode)

*Warning: These commands bypass safety checks.*

| Command | Arguments | Description | 
 | ----- | ----- | ----- | 
| `heater` | `on` / `off` | Manually toggle SSR. | 
| `pump` | `on` / `off` | Manually toggle Pump Relay. | 
| `fillvalve` | `on` / `off` | Manually toggle Solenoid. | 
| `dimmer` | `0-100` | Set pump Triac power percentage. | 
| `pidoutput` | `0-100` / `auto` | Force manual heater duty cycle or return to Auto. | 
| `readadc` | `0-3` | Read raw ADS1115 voltage on channel X. | 
| `readweight` |  | Read raw ADS1232 scale data. | 

## 4. MQTT Topic Reference

**Broker Configuration:** Set via the WiFi portal or `set` command.
**Root Topic:** `espresso/`

### Status & Sensors (Read-Only)

| Topic | Payload | Description | 
 | ----- | ----- | ----- | 
| `status/state` | String | Current Machine State. | 
| `status/brew_mode` | `COFFEE`/`STEAM` | Current Brew Mode. | 
| `status/steam_boost` | `true`/`false` | Steam boost active status. | 
| `sensor/boiler_temp` | Float | Main Boiler Temp (°C). | 
| `sensor/hx_temp` | Float | Group/HX Temp (°C). | 
| `sensor/pressure` | Float | Pressure (Bar). | 
| `sensor/weight` | Float | Scale Weight (g). | 
| `sensor/flow_rate` | Float | Flow Rate (g/s). | 
| `sensor/heater` | `ON`/`OFF` | SSR State. | 
| `sensor/pump` | `ON`/`OFF` | Pump Relay State. | 
| `sensor/lever` | `LIFTED`/`DOWN` | Brew Lever State. | 
| `sensor/pidoutput` | Float | Heater Duty Cycle (%). | 
| `sensor/pterm` | Float | PID Proportional Term (Debug). | 
| `sensor/iterm` | Float | PID Integral Term (Debug). | 
| `sensor/dterm` | Float | PID Derivative Term (Debug). | 

Notes: 
 1) BrewMode `STEAM` is similar to a "standard" heatexchanger machine. It heats up much faster and is basically a bang-bang controller (it is a bit smarter than that). Expect, however, that the temperature fluctuates more in this mode. In this mode the machine will do occasional cooling flushes (just like the MaraX standard firmware does). Brewmode `COFFEE` uses the PID to turn the heater on off. It ramps to the target temperature slower but keeps the temperature much more stable.
 2) SteamBoost refers to the behaviour after the shot. If enabled the machine will turn on the heater full blast for 15s after a shot which increases the steam pressure. In turn the temperature of the heatexchanger will fluctuate. If you want to to do a single shot with foamed milk, use this mode. If you want to do multiple shots maybe not. 

### Control & Configuration (Write-Only)

**Topic:** `espresso/settings/set`
**Payload Format:** `key=value`

#### Temperature Settings

* `tempsetbrew=93.0` (Target Brew Temp)

* `tempsetsteam=135.0` (Target Steam Temp)

* `tempsetsteamboost=125.0` (Boost Temp after shot)

* `steamboost=true` (Enable/Disable boost feature)

#### PID Tuning

* `kp_temperature`, `ki_temperature`, `kd_temperature`

* `kp_pressure`, `ki_pressure`, `kd_pressure`

* `kp_flow`, `ki_flow`, `kd_flow`

#### Profiling Configuration

* `profiling_mode`: `manual`, `flat`, or `profile`.

* `profiling_target`: `time` or `weight` (X-axis source).

* `profiling_source`: `pressure` or `flow` (Y-axis control).

* `profiling_flat_value`: Float (e.g., `9.0` for 9 bar flat profile).

#### Operations

* `tare_scale=true`: Tare the scale.

* `start_cleaning=true`: Start the 10-step backflush cycle.

* `request=true`: Request the machine to republish all settings.

## 5. Profiling Data Structure

To upload a complex shot profile, send a JSON payload to `espresso/settings/set` with the key `profile_data`.

**JSON Structure:**

```json
{
  "n": "Profile Name",  // String: Name of profile
  "m": 1,               // Int: 0 = Ramped (Interpolated), 1 = Stepped (Hard jumps)
  "s": [                // Array: List of steps
    [9.0, 5.0],         // [Setpoint, Trigger]
    [6.0, 15.0]
  ]
}
```

**Understanding "Trigger":**

* If `profiling_target` is `time`: Trigger is **duration** of step in seconds.

* If `profiling_target` is `weight`: Trigger is **target weight** in grams.

**Understanding "Setpoint":**

* If `profiling_source` is `pressure`: Setpoint is **Bar**.

* If `profiling_source` is `flow`: Setpoint is **mL/s**.

**Example Payload:**
`profile_data={"n":"Soft Preinfusion","m":1,"s":[[2.0,5.0],[9.0,25.0]]}`
*(2 Bar for 5 seconds, then 9 Bar for 25 seconds)*

## 6. HomeAssistant integration
If you want to use home assistant integration the following is a working MQTT section in `configuration.yaml` that can be used in HomeAssistant to tie in the smart coffee machine. 

      mqtt:
        sensor:
          - name: "Heatexchanger Temperature"
            unique_id: espresso_machine_hx_temp
            state_topic: "espresso/sensor/hx_temp"
            unit_of_measurement: "°C"
            device_class: "temperature"
            state_class: "measurement"
            device:
              identifiers: ["espresso_mqtt"]
              name: "Lelit Mara X V2"
              manufacturer: "Lelit"
              model: "Mara X V2"
          - name: "Boiler Temperature"
            unique_id: espresso_machine_boiler_temp
            state_topic: "espresso/sensor/boiler_temp"
            unit_of_measurement: "°C"
            device_class: "temperature"
            state_class: "measurement"
            device:
              identifiers: ["espresso_mqtt"]
              name: "Lelit Mara X V2"
              manufacturer: "Lelit"
              model: "Mara X V2"
          - name: "Temperature PID output"
            unique_id: espresso_machine_temperature_pidoutput
            state_topic: "espresso/sensor/pidoutput"
            state_class: "measurement"
            device:
              identifiers: ["espresso_mqtt"]
              name: "Lelit Mara X V2"
              manufacturer: "Lelit"
              model: "Mara X V2"
          - name: "Temperature PID P Integrator"
            unique_id: espresso_machine_temperature_pint
            state_topic: "espresso/sensor/pterm"
            state_class: "measurement"
            device:
              identifiers: ["espresso_mqtt"]
              name: "Lelit Mara X V2"
              manufacturer: "Lelit"
              model: "Mara X V2"
          - name: "Temperature PID I Integrator"
            unique_id: espresso_machine_temperature_iint
            state_topic: "espresso/sensor/iterm"
            state_class: "measurement"
            device:
              identifiers: ["espresso_mqtt"]
              name: "Lelit Mara X V2"
              manufacturer: "Lelit"
              model: "Mara X V2"
          - name: "Temperature PID D Integrator"
            unique_id: espresso_machine_temperature_dint
            state_topic: "espresso/sensor/dterm"
            state_class: "measurement"
            device:
              identifiers: ["espresso_mqtt"]
              name: "Lelit Mara X V2"
              manufacturer: "Lelit"
              model: "Mara X V2"
          - name: "Pressure"
            unique_id: espresso_pressure
            state_topic: "espresso/sensor/pressure"
            unit_of_measurement: "bar"
            device_class: "pressure"
            state_class: "measurement"
            device:
              identifiers: ["espresso_mqtt"]
              name: "Lelit Mara X V2"
              manufacturer: "Lelit"
              model: "Mara X V2"
          - name: "Machine State"
            unique_id: espresso_machine_state
            state_topic: "espresso/status/state"
            icon: mdi:coffee
            device:
              identifiers: ["espresso_mqtt"]
              name: "Lelit Mara X V2"
              manufacturer: "Lelit"
              model: "Mara X V2"
          - name: "Weight"
            unique_id: espresso_machine_weight
            state_topic: "espresso/sensor/weight"
            unit_of_measurement: "g"
            device_class: "weight"
            state_class: "measurement"
            icon: mdi:weight-gram
            device:
              identifiers: ["espresso_mqtt"]
              name: "Lelit Mara X V2"
              manufacturer: "Lelit"
              model: "Mara X V2"
          - name: "Flow Rate"
            unique_id: espresso_machine_flow_rate
            state_topic: "espresso/sensor/flow_rate"
            unit_of_measurement: "g/s"
            state_class: "measurement"
            icon: mdi:water-pump
            device:
              identifiers: ["espresso_mqtt"]
              name: "Lelit Mara X V2"
              manufacturer: "Lelit"
              model: "Mara X V2"
      
        binary_sensor:
          - name: "Heating"
            unique_id: espresso_heating
            state_topic: "espresso/sensor/heater"
            payload_on: "ON"
            payload_off: "OFF"
            device_class: "heat"
            device:
              identifiers: ["espresso_mqtt"]
              name: "Lelit Mara X V2"
              manufacturer: "Lelit"
              model: "Mara X V2"
          - name: "Pump"
            unique_id: espresso_pump
            state_topic: "espresso/sensor/pump"
            payload_on: "ON"
            payload_off: "OFF"
            device_class: "running"
            device:
              identifiers: ["espresso_mqtt"]
              name: "Lelit Mara X V2"
              manufacturer: "Lelit"
              model: "Mara X V2"
          - name: "Lever"
            unique_id: espresso_lever
            state_topic: "espresso/sensor/lever"
            payload_on: "LIFTED"
            payload_off: "DOWN"
            icon: mdi:electric-switch
            device:
              identifiers: ["espresso_mqtt"]
              name: "Lelit Mara X V2"
              manufacturer: "Lelit"
              model: "Mara X V2"
      
        select:
          - name: "Brewmode"
            unique_id: espresso_brewmode_select # Use a new unique_id
            state_topic: "espresso/status/brew_mode"
            command_topic: "espresso/settings/set"
            # This template takes the selected option and formats it for your ESP32
            command_template: "brewmode={{ value | lower }}"
            value_template: "{{ value | upper }}"
            # This is the list of options that will appear in the dropdown
            options:
              - "COFFEE"
              - "STEAM"
            icon: mdi:coffee
            device:
              identifiers: ["espresso_mqtt"]
              name: "Lelit Mara X V2"
              manufacturer: "Lelit"
              model: "Mara X V2"
          - name: "Profiling Mode"
            unique_id: espresso_profmode_select # Use a new unique_id
            state_topic: "espresso/settings/status/profiling_mode"
            command_topic: "espresso/settings/set"
            # This template takes the selected option and formats it for your ESP32
            command_template: "profiling_mode={{ value | lower }}"
            value_template: "{{ value | upper }}"
            # This is the list of options that will appear in the dropdown
            options:
              - "MANUAL"
              - "FLAT"
              - "PROFILE"
            icon: mdi:coffee
            device:
              identifiers: ["espresso_mqtt"]
              name: "Lelit Mara X V2"
              manufacturer: "Lelit"
              model: "Mara X V2"
          - name: "Profiling Control"
            unique_id: espresso_profTarget_select # Use a new unique_id
            state_topic: "espresso/settings/status/profiling_target"
            command_topic: "espresso/settings/set"
            # This template takes the selected option and formats it for your ESP32
            command_template: "profiling_target={{ value | lower }}"
            value_template: "{{ value | upper }}"
            # This is the list of options that will appear in the dropdown
            options:
              - "TIME"
              - "WEIGHT"
            icon: mdi:coffee
            device:
              identifiers: ["espresso_mqtt"]
              name: "Lelit Mara X V2"
              manufacturer: "Lelit"
              model: "Mara X V2"
          - name: "Profiling Target"
            unique_id: espresso_profSource_select # Use a new unique_id
            state_topic: "espresso/settings/status/profiling_source"
            command_topic: "espresso/settings/set"
            # This template takes the selected option and formats it for your ESP32
            command_template: "profiling_source={{ value | lower }}"
            value_template: "{{ value | upper }}"
            # This is the list of options that will appear in the dropdown
            options:
              - "PRESSURE"
              - "FLOW"
            icon: mdi:coffee
            device:
              identifiers: ["espresso_mqtt"]
              name: "Lelit Mara X V2"
              manufacturer: "Lelit"
              model: "Mara X V2"
        switch:
          - name: "Steamboost"
            unique_id: espresso_steamboost
            state_topic: "espresso/status/steam_boost"
            payload_on: "true"
            payload_off: "false"
            command_topic: "espresso/settings/set"
            command_template: "{{ 'enablesteamboost=true' if value == 'true' else 'enablesteamboost=false'}}"
            retain: true
            device:
              identifiers: ["espresso_mqtt"]
              name: "Lelit Mara X V2"
              manufacturer: "Lelit"
              model: "Mara X V2"
        button:
          - name: "Start cleaning cycle"
            unique_id: espresso_cleaning
            command_topic: "espresso/settings/set"
            command_template: "start_cleaning=true"
            retain: false
            device:
              identifiers: ["espresso_mqtt"]
              name: "Lelit Mara X V2"
              manufacturer: "Lelit"
              model: "Mara X V2"
          - name: "Tare Scale"
            unique_id: espresso_tare_scale
            command_topic: "espresso/settings/set"
            command_template: "tare_scale=true"
            retain: false
            icon: mdi:scale
            device:
              identifiers: ["espresso_mqtt"]
              name: "Lelit Mara X V2"
              manufacturer: "Lelit"
              model: "Mara X V2"
          - name: "Scale Calibration"
            unique_id: espresso_start_calibration
            command_topic: "espresso/settings/set"
            command_template: >
              {% if states('sensor.lelit_mara_x_v2_machine_state').startswith('CALIBRATION_') %}
                calibration_step={{ states('number.lelit_mara_x_v2_calibrate_scale_test_weight') }}
              {% else %}
                calibratescale=true
              {% endif %}
            retain: false
            icon: mdi:scale-balance
            device:
              identifiers: ["espresso_mqtt"]
              name: "Lelit Mara X V2"
              manufacturer: "Lelit"
              model: "Mara X V2"
        number:
          - name: "Brew Target Temperature"
            unique_id: espresso_tempsetbrew
            state_topic: "espresso/settings/status/tempsetbrew"
            command_topic: "espresso/settings/set"
            command_template: "tempsetbrew={{ value }}"
            min: 80
            max: 100
            step: 0.1
            mode: slider
            unit_of_measurement: "°C"
            device_class: "temperature"
            device:
              identifiers: ["espresso_mqtt"]
              name: "Lelit Mara X V2"
              manufacturer: "Lelit"
              model: "Mara X V2"
      
          - name: "Steam Target Temperature"
            unique_id: espresso_tempsetsteam
            state_topic: "espresso/settings/status/tempsetsteam"
            command_topic: "espresso/settings/set"
            command_template: "tempsetsteam={{ value }}"
            min: 110
            max: 133
            step: 0.1
            mode: slider
            unit_of_measurement: "°C"
            device_class: "temperature"
            device:
              identifiers: ["espresso_mqtt"]
              name: "Lelit Mara X V2"
              manufacturer: "Lelit"
              model: "Mara X V2"
      
          - name: "Steamboost Target Temperature"
            unique_id: espresso_tempsetsteamboost
            state_topic: "espresso/settings/status/tempsetsteamboost"
            command_topic: "espresso/settings/set"
            command_template: "tempsetsteamboost={{ value }}"
            min: 100
            max: 133
            step: 0.1
            mode: slider
            unit_of_measurement: "°C"
            device_class: "temperature"
            device:
              identifiers: ["espresso_mqtt"]
              name: "Lelit Mara X V2"
              manufacturer: "Lelit"
              model: "Mara X V2"
      
          # --- NEW: Brew PID Settings ---
          - name: "PID Temperature Kp"
            unique_id: espresso_kp_brew
            state_topic: "espresso/settings/status/kp_temperature"
            command_topic: "espresso/settings/set"
            command_template: "kp_temperature={{ value }}"
            min: 0
            max: 10
            step: 0.01
            mode: slider
            device:
              identifiers: ["espresso_mqtt"]
              name: "Lelit Mara X V2"
              manufacturer: "Lelit"
              model: "Mara X V2"
      
          - name: "PID Temperature Ki"
            unique_id: espresso_ki_brew
            state_topic: "espresso/settings/status/ki_temperature"
            command_topic: "espresso/settings/set"
            command_template: "ki_temperature={{ value | float /1000 }}"
            value_template: "{{ value | float *1000}}"
            min: 0
            max: 10
            step: 0.001
            mode: slider
            device:
              identifiers: ["espresso_mqtt"]
              name: "Lelit Mara X V2"
              manufacturer: "Lelit"
              model: "Mara X V2"
      
          - name: "PID Temperature Kd"
            unique_id: espresso_kd_brew
            state_topic: "espresso/settings/status/kd_temperature"
            command_topic: "espresso/settings/set"
            command_template: "kd_temperature={{ value | float *1000 }}"
            value_template: "{{ value | float /1000 }}"
            min: 0
            max: 10
            step: 0.1
            mode: slider
            device:
              identifiers: ["espresso_mqtt"]
              name: "Lelit Mara X V2"
              manufacturer: "Lelit"
              model: "Mara X V2"
          - name: "Profiling Flat Target"
            unique_id: espresso_profiling_flat_value
            state_topic: "espresso/settings/status/profiling_flat_value"
            command_topic: "espresso/settings/set"
            command_template: "profiling_flat_value={{ value }}"
            min: 0
            max: 100 # Assuming 100 is max (e.g., pressure or flow)
            step: 0.5
            mode: slider
            icon: mdi:chart-line-variant
            device:
              identifiers: ["espresso_mqtt"]
              name: "Lelit Mara X V2"
              manufacturer: "Lelit"
              model: "Mara X V2"
      
          # --- PID Pressure ---
          - name: "PID Pressure Kp"
            unique_id: espresso_kp_pressure
            state_topic: "espresso/settings/status/kp_pressure"
            command_topic: "espresso/settings/set"
            command_template: "kp_pressure={{ value }}"
            min: 0
            max: 50
            step: 0.01
            mode: slider
            device:
              identifiers: ["espresso_mqtt"]
              name: "Lelit Mara X V2"
              manufacturer: "Lelit"
              model: "Mara X V2"
          - name: "PID Pressure Ki"
            unique_id: espresso_ki_pressure
            state_topic: "espresso/settings/status/ki_pressure"
            command_topic: "espresso/settings/set"
            command_template: "ki_pressure={{ value }}"
            min: 0
            max: 50
            step: 0.1
            mode: slider
            device:
              identifiers: ["espresso_mqtt"]
              name: "Lelit Mara X V2"
              manufacturer: "Lelit"
              model: "Mara X V2"
          - name: "PID Pressure Kd"
            unique_id: espresso_kd_pressure
            state_topic: "espresso/settings/status/kd_pressure"
            command_topic: "espresso/settings/set"
            command_template: "kd_pressure={{ value }}"
            min: 0
            max: 50
            step: 0.01
            mode: slider
            device:
              identifiers: ["espresso_mqtt"]
              name: "Lelit Mara X V2"
              manufacturer: "Lelit"
              model: "Mara X V2"
      
          # --- PID Flow ---
          - name: "PID Flow Kp"
            unique_id: espresso_kp_flow
            state_topic: "espresso/settings/status/kp_flow"
            command_topic: "espresso/settings/set"
            command_template: "kp_flow={{ value }}"
            min: 0
            max: 10
            step: 0.1
            mode: slider
            device:
              identifiers: ["espresso_mqtt"]
              name: "Lelit Mara X V2"
              manufacturer: "Lelit"
              model: "Mara X V2"
          - name: "PID Flow Ki"
            unique_id: espresso_ki_flow
            state_topic: "espresso/settings/status/ki_flow"
            command_topic: "espresso/settings/set"
            command_template: "ki_flow={{ value }}"
            min: 0
            max: 10
            step: 0.1
            mode: slider
            device:
              identifiers: ["espresso_mqtt"]
              name: "Lelit Mara X V2"
              manufacturer: "Lelit"
              model: "Mara X V2"
          - name: "PID Flow Kd"
            unique_id: espresso_kd_flow
            state_topic: "espresso/settings/status/kd_flow"
            command_topic: "espresso/settings/set"
            command_template: "kd_flow={{ value }}"
            min: 0
            max: 10
            step: 0.1
            mode: slider
            device:
              identifiers: ["espresso_mqtt"]
              name: "Lelit Mara X V2"
              manufacturer: "Lelit"
              model: "Mara X V2"
      
          # --- Kalman Weight ---
          - name: "Kalman Weight Measurement Error"
            unique_id: espresso_weight_kalman_me
            state_topic: "espresso/settings/status/weight_kalman_me"
            command_topic: "espresso/settings/set"
            command_template: "weight_kalman_me={{ value }}"
            min: 0
            max: 20
            step: 0.1
            mode: slider
            device:
              identifiers: ["espresso_mqtt"]
              name: "Lelit Mara X V2"
              manufacturer: "Lelit"
              model: "Mara X V2"
          - name: "Kalman Weight Estimate Error"
            unique_id: espresso_weight_kalman_e
            state_topic: "espresso/settings/status/weight_kalman_e"
            command_topic: "espresso/settings/set"
            command_template: "weight_kalman_e={{ value }}"
            min: 0
            max: 20
            step: 0.1
            mode: slider
            device:
              identifiers: ["espresso_mqtt"]
              name: "Lelit Mara X V2"
              manufacturer: "Lelit"
              model: "Mara X V2"
          - name: "Kalman Weight Process Noise"
            unique_id: espresso_weight_kalman_q
            state_topic: "espresso/settings/status/weight_kalman_q"
            command_topic: "espresso/settings/set"
            command_template: "weight_kalman_q={{ value }}"
            min: 0
            max: 1
            step: 0.01
            mode: slider
            device:
              identifiers: ["espresso_mqtt"]
              name: "Lelit Mara X V2"
              manufacturer: "Lelit"
              model: "Mara X V2"
      
          # --- Kalman Flow ---
          - name: "Kalman Flow Measurement Error"
            unique_id: espresso_flow_kalman_me
            state_topic: "espresso/settings/status/flow_kalman_me"
            command_topic: "espresso/settings/set"
            command_template: "flow_kalman_me={{ value }}"
            min: 0
            max: 50
            step: 0.1
            mode: slider
            device:
              identifiers: ["espresso_mqtt"]
              name: "Lelit Mara X V2"
              manufacturer: "Lelit"
              model: "Mara X V2"
          - name: "Kalman Flow Estimate Error"
            unique_id: espresso_flow_kalman_e
            state_topic: "espresso/settings/status/flow_kalman_e"
            command_topic: "espresso/settings/set"
            command_template: "flow_kalman_e={{ value }}"
            min: 0
            max: 50
            step: 0.1
            mode: slider
            device:
              identifiers: ["espresso_mqtt"]
              name: "Lelit Mara X V2"
              manufacturer: "Lelit"
              model: "Mara X V2"
          - name: "Kalman Flow Process Noise"
            unique_id: espresso_flow_kalman_q
            state_topic: "espresso/settings/status/flow_kalman_q"
            command_topic: "espresso/settings/set"
            command_template: "flow_kalman_q={{ value }}"
            min: 0
            max: 1
            step: 0.01
            mode: slider
            device:
              identifiers: ["espresso_mqtt"]
              name: "Lelit Mara X V2"
              manufacturer: "Lelit"
              model: "Mara X V2"
          - name: "Calibrate Scale Test Weight"
            unique_id: espress_calibrate_test_weight
            command_topic: "espresso/dummy/variable_set"
            optimistic: true
            min: 1
            max: 750
            step: 0.5
            retain: true
            mode: box
            icon: mdi:counter
            device:
              identifiers: ["espresso_mqtt"]
              name: "Lelit Mara X V2"
              manufacturer: "Lelit"
              model: "Mara X V2"

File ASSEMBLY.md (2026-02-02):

# Assembly Instructions

> [!DANGER]
> **SAFETY WARNING:** Disconnect your coffee machine from mains voltage before attempting any modifications! Working with high voltage is dangerous.

## Phase 1: PCB Assembly

### 1. Receive and Inspect Boards
[PCBs as arrived from factory](https://github.com/user-attachments/assets/b2bef99c-e74c-4d39-bb34-1229ab425327)

If you ordered SMT assembly (e.g., from JLCPCB), your boards should arrive in the condition shown above. Note that several small SMD parts will still require manual soldering.

### 2. Controller Board Assembly
[Assembled controller board](https://github.com/user-attachments/assets/12f04637-929b-4e32-97e9-930ab41f4924)

Above is the fully assembled controller board. 

**Key Assembly Notes:**
* **Socketing:** The **LM1830** chip and the **AQV212** chip can be socketed as shown in the picture.
* **Arduino Nano:** In the picture the Arduino Nano is also socketed (too many have been destroyed during testing), but be mindful about vertical space constraints. Standard headers are too tall. Use **Mil-max (low profile) sockets** to ensure the board fits inside the housing.
* *(Please ignore the "dodgy" soldering in the reference photo—a hot air station is recommended for cleaner results!)*

### 3. HV-Board Assembly
[Assembled HV board](https://github.com/user-attachments/assets/1e37c6e1-696d-41fc-987f-07d94724000b)

Above is the fully assembled High Voltage (HV) board.

**Key Assembly Notes:**
* **Heatspreader:** You may need to trim/cut down the heatspreader on the **TRIAC** to ensure there is enough vertical clearance within the enclosure.
* **Order of Operations:** It is highly suggested to solder all missing SMD parts (such as the Fuse) **before** soldering the bulky components like the Relays and the Power Supply.

---

## Phase 2: Housing & Preparation

### 4. Gicar Box Retrofit
[Gicar box bottom view 1](https://github.com/user-attachments/assets/f11d798c-b8f2-4f87-a943-a14a00daa7bc)
[Gicar box bottom view 2](https://github.com/user-attachments/assets/999779a8-40dc-4ba7-b476-8f0ee90f952a)

Repurpose the existing Gicar control box. As shown in the bottom views above, all connectors should fit neatly through the existing holes without modification to the plastic.

---

## Phase 3: Pressure Transducer (Optional)

*Note: The following three steps are only relevant if you are installing the optional pressure transducer.*

### 5. Tubing Installation
[Transducer molex connector](https://github.com/user-attachments/assets/a6955f76-337c-45ba-98c9-09f81a4d1a6b)

Replace the existing transparent silicone tube with a **5mm polyurethane tube (food grade)**. Tie your pressure transducer into the circuit as shown in the image.

### 6. Pump Wiring Modification
[Pressure transducer tubing](https://github.com/user-attachments/assets/bf58da85-ba2a-4dcf-aa4a-16d0d0918a21)
[Pump wiring modification](https://github.com/user-attachments/assets/be84fa4f-fe3a-4688-a5c8-f4e108196a9e)

1.  Unplug the **Brown** (Live) wire from the pump.
2.  Connect your own custom wire to the pump's Live terminal instead.
3.  This new wire will connect to the modified Gicar box (detailed in Phase 4).

### 7. Transducer Connection
[Transducer molex connector5](https://github.com/user-attachments/assets/9462ca87-df7b-42ad-8284-b255f486efc5)

Terminate the pressure transducer wires with a Molex connector. This will mate with the corresponding header on the controller board. Make sure the order is exactly as shown in the picture with red being 12V, black being GND and yellow the signal cable.

---

## Phase 4: Final Wiring

### 8. High Voltage (Faston) Connections
[Bottom controller connections](https://github.com/user-attachments/assets/db68a03c-02f9-4e8a-b33e-5b859a19b8ac)

Connect the Faston tabs to the Gicar box.

> [!WARNING]
> **Important:** The original schematic printed on the Gicar box plastic is **NO LONGER CORRECT**. You must follow the new pinout order below.

**Pinout Order (Left to Right / as shown):**
1.  **230V Live Wire**
2.  **230V Neutral Wire**
3.  **Pump Live Wire**
4.  **Custom Pump Dimmer Wire** (The cable you created in Step 6)
5.  **Coffee Relay Live Wire**

### 9. Top Controller Connections
[Gicar box Faston connections](https://github.com/user-attachments/assets/f80dea4b-8075-4388-870e-5d993e090e9b)

On the top side of the controller board, connect the existing machine connectors in the following order:

* **Boiler Temperature Sensor**
* **Boiler Fill Sensor**
* **Heater SSR Relay**
* **Brew Lever Sensor**

### 10. Bottom Controller Connections (Low Voltage)
[Final assembly view](https://github.com/user-attachments/assets/c3b830b4-7888-44e8-86a4-bd78d6e86eda)

Connect the low voltage peripherals to the bottom of the board in the following order:

* **Water Level Sensor (Tank)**
* **Heat Exchanger (HX) Temperature Sensor**
* **LEDs and Switch Sensors**
* **Custom Pressure Transducer**
* **Custom Scale Cable** *(Refer to the separate Tray Scale repository for scale installation instructions)*

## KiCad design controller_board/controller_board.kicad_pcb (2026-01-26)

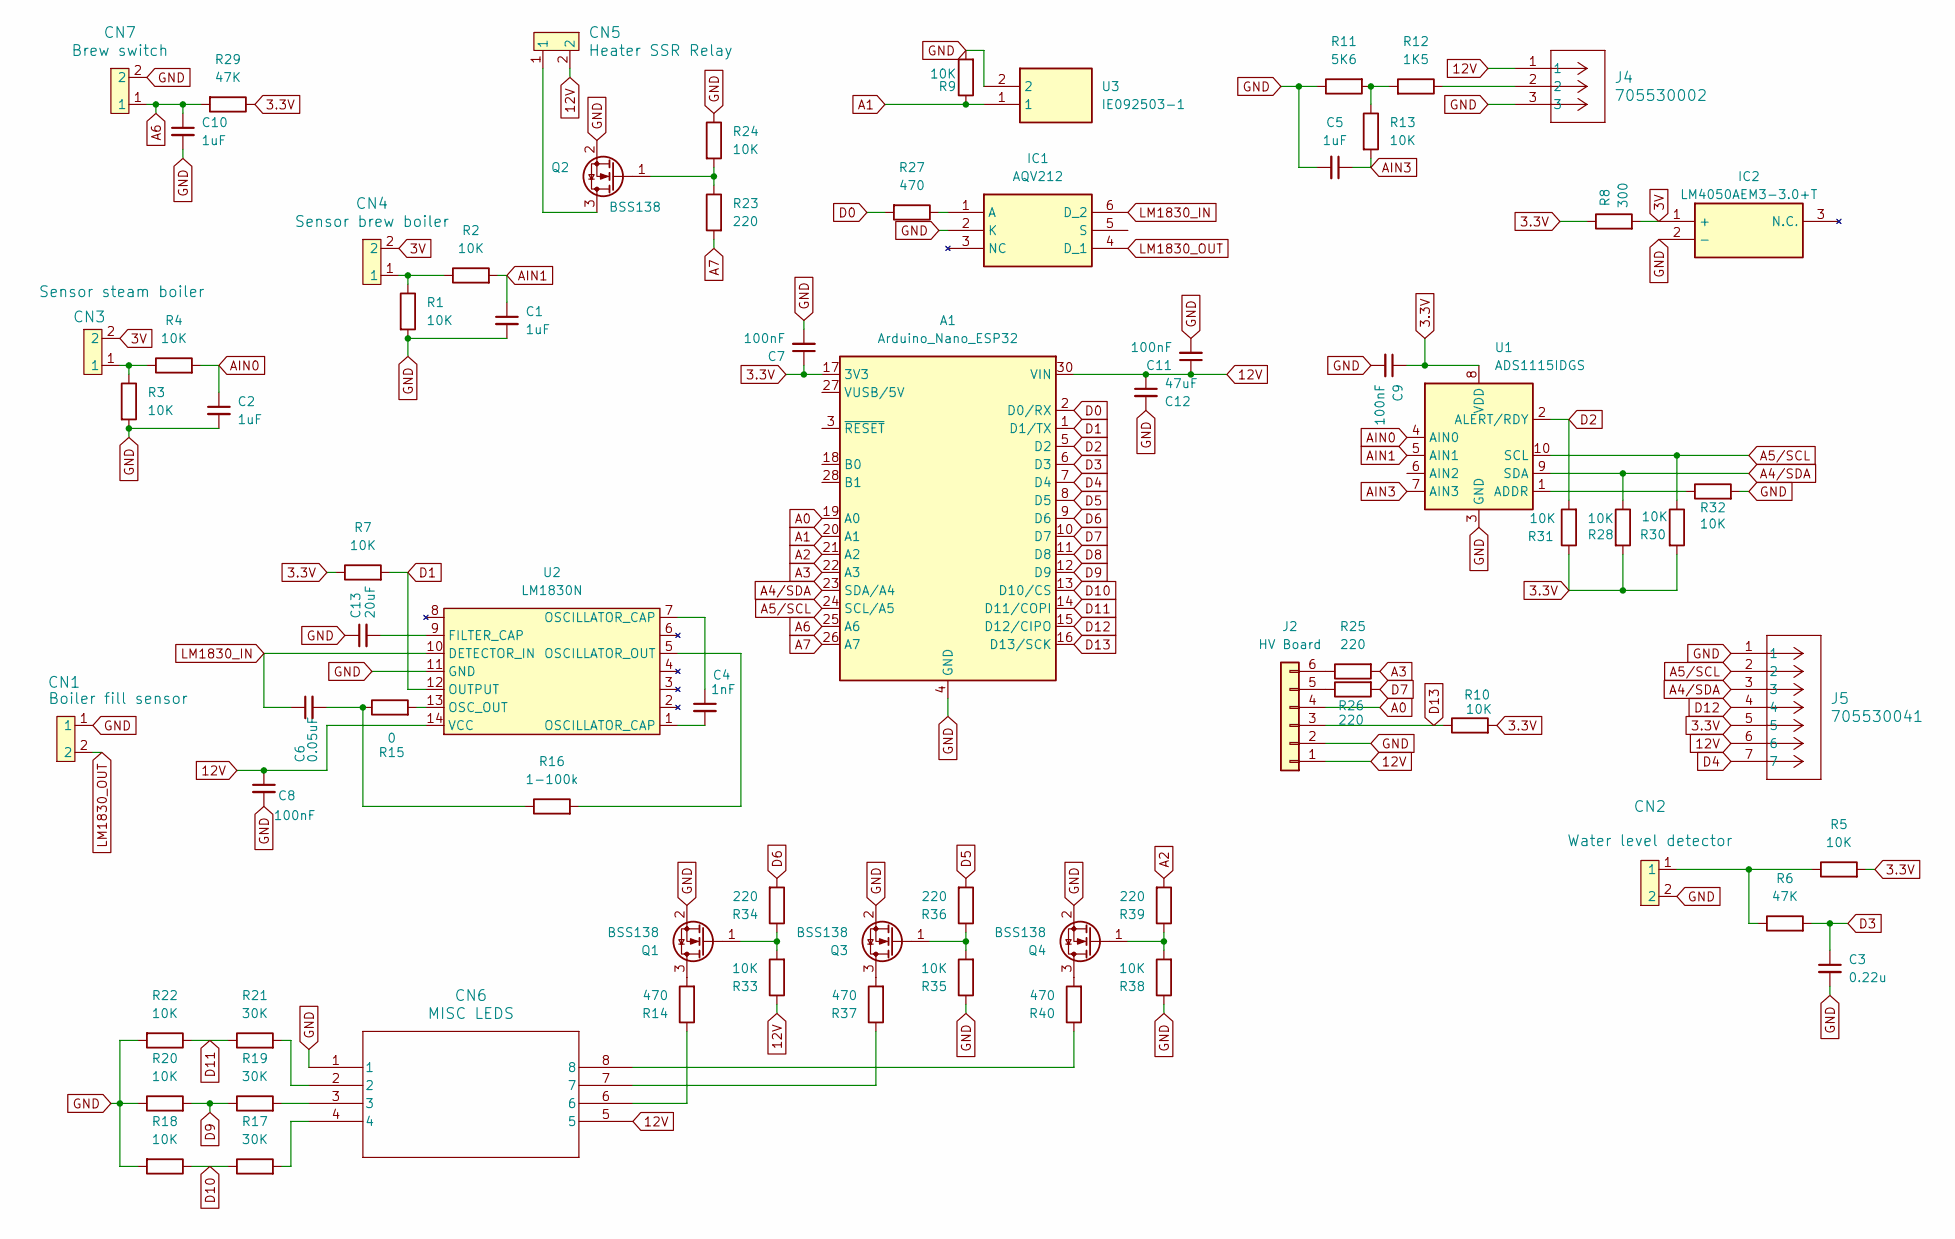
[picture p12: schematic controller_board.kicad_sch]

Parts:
A1: Arduino_Nano_ESP32; Arduino_Nano
C1, C2, C5, C10: 1uF; C_0805_2012Metric_Pad1.18x1.45mm_HandSolder
C3: 0.22u; C_0805_2012Metric_Pad1.18x1.45mm_HandSolder
C4: 1nF; C_0805_2012Metric_Pad1.18x1.45mm_HandSolder
C6: 0.05uF; C_0805_2012Metric_Pad1.18x1.45mm_HandSolder
C7, C8, C9, C11: 100nF; C_0805_2012Metric_Pad1.18x1.45mm_HandSolder
C12: 47uF; C_0805_2012Metric_Pad1.18x1.45mm_HandSolder
C13: 20uF; C_0805_2012Metric_Pad1.18x1.45mm_HandSolder
CN1: Boiler fill sensor; 280377-2_TYC
CN2: Water level detector; 280377-2_TYC
CN3: Sensor steam boiler; 280377-2_TYC
CN4: Sensor brew boiler; 280377-2_TYC
CN5: Heater SSR Relay; 280377-2_TYC
CN6: MISC LEDS; 280389-2_TYC
CN7: Brew switch; 280377-2_TYC
IC1: AQV212; DIP762W47P254L880H410Q6N; Mouser Part Number 769-AQV212
IC2: LM4050AEM3-3.0+T; SOT95P237X112-3N; Mouser Part Number 700-LM4050AEM3-3.0T
J2: HV Board; PinHeader_1x06_P2.00mm_Vertical
J4: 705530002; CONN_705530002_03_MOL
J5: 705530041; CONN_70553-xxxx_07_MOL
Q1, Q2, Q3, Q4: BSS138; SOT-23
R1, R2, R3, R4, R5, R7, R9, R10, R13, R18, R20, R22, R24, R28, R30, R31, R32, R33, R35, R38: 10K; R_0805_2012Metric_Pad1.20x1.40mm_HandSolder
R6, R29: 47K; R_0805_2012Metric_Pad1.20x1.40mm_HandSolder
R8: 300; R_0805_2012Metric_Pad1.20x1.40mm_HandSolder
R11: 5K6; R_0805_2012Metric_Pad1.20x1.40mm_HandSolder
R12: 1K5; R_0805_2012Metric_Pad1.20x1.40mm_HandSolder
R14, R27, R37, R40: 470; R_0805_2012Metric_Pad1.20x1.40mm_HandSolder
R15: 0; R_0805_2012Metric_Pad1.20x1.40mm_HandSolder
R16: 1-100k; R_0805_2012Metric_Pad1.20x1.40mm_HandSolder
R17, R19, R21: 30K; R_0805_2012Metric_Pad1.20x1.40mm_HandSolder
R23, R25, R26, R34, R36, R39: 220; R_0805_2012Metric_Pad1.20x1.40mm_HandSolder
U1: ADS1115IDGS; VSSOP-10_3x3mm_P0.5mm
U2: LM1830N; PDIP14_19P56X6P35_ONS
U3: IE092503-1; IE0925031; Mouser Part Number 497-IE092503-1

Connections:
3.3V: A1.17 (3V3), C7.1, C9.1, J5.5, R5.2, R7.1, R8.1, R10.2, R28.2, R29.1, R30.2, R31.1, U1.8 (VDD)
3V: CN3.2, CN4.2, IC2.1 (+), R8.2
12V: A1.30 (VIN), C8.1, C11.1, C12.1, CN5.2, CN6.5, J2.1, J4.1, J5.6, R33.1, U2.14 (VCC)
A0: A1.19 (A0), J2.4
A1: A1.20 (A1), R9.1, U3.1
A2: A1.21 (A2), R39.2
A3: A1.22 (A3), R25.2
A4/SDA: A1.23 (SDA/A4), J5.3, R28.1, U1.9 (SDA)
A5/SCL: A1.24 (SCL/A5), J5.2, R30.1, U1.10 (SCL)
A6: A1.25 (A6), C10.1, CN7.1, R29.2
A7: A1.26 (A7), R23.2
AIN0: C2.1, R4.2, U1.4 (AIN0)
AIN1: C1.1, R2.2, U1.5 (AIN1)
AIN3: C5.1, R13.2, U1.7 (AIN3)
D0: A1.2 (D0/RX), R27.2
D1: A1.1 (D1/TX), R7.2, U2.12 (OUTPUT)
D2: A1.5 (D2), R31.2, U1.2 (ALERT/RDY)
D3: A1.6 (D3), C3.1, R6.2
D4: A1.7 (D4), J5.7
D5: A1.8 (D5), R36.2
D6: A1.9 (D6), R34.2
D7: A1.10 (D7), R26.2
D8: A1.11 (D8)
D9: A1.12 (D9), R19.1, R20.2
D10: A1.13 (D10/CS), R17.1, R18.1
D11: A1.14 (D11/COPI), R21.1, R22.1
D12: A1.15 (D12/CIPO), J5.4
D13: A1.16 (D13/SCK), J2.3, R10.1
GND: A1.4 (GND), A1.29 (GND), C1.2, C2.2, C3.2, C5.2, C7.2, C8.2, C9.2, C10.2, C11.2, C12.2, C13.1, CN1.1, CN2.2, CN6.1, CN7.2, IC1.2 (K), IC2.2 (-), J2.2, J4.3, J5.1, Q1.2 (S), Q2.2 (S), Q3.2 (S), Q4.2 (S), R1.2, R3.2, R9.2, R11.1, R18.2, R20.1, R22.2, R24.1, R32.2, R35.1, R38.1, U1.3 (GND), U2.11 (GND), U3.2
LM1830_IN: C6.1, IC1.6 (D_2), U2.10 (DETECTOR_IN)
LM1830_OUT: CN1.2, IC1.4 (D_1)
unnamed: C4.1, U2.7 (OSCILLATOR_CAP)
unnamed: C4.2, U2.1 (OSCILLATOR_CAP)
unnamed: C6.2, R15.1, R16.1
unnamed: CN2.1, R5.1, R6.1
unnamed: CN3.1, R3.1, R4.1
unnamed: CN4.1, R1.1, R2.1
unnamed: CN6.2, R21.2
unnamed: CN6.3, R19.2
unnamed: CN6.4, R17.2
unnamed: CN6.6, R14.1
unnamed: CN6.7, R37.1
unnamed: CN6.8, R40.1
unnamed: IC1.1 (A), R27.1
unnamed: J2.5, R26.1
unnamed: J2.6, R25.1
unnamed: J4.2, R12.1
unnamed: Q1.3 (D), R14.2
unnamed: Q1.1 (G), R33.2, R34.1
unnamed: CN5.1, Q2.3 (D)
unnamed: Q2.1 (G), R23.1, R24.2
unnamed: Q3.3 (D), R37.2
unnamed: Q3.1 (G), R35.2, R36.1
unnamed: Q4.3 (D), R40.2
unnamed: Q4.1 (G), R38.2, R39.1
unnamed: R11.2, R12.2, R13.1
unnamed: R32.1, U1.1 (ADDR)
unnamed: C13.2, U2.9 (FILTER_CAP)
unnamed: R16.2, U2.5 (OSCILLATOR_OUT)
unnamed: R15.2, U2.13 (OSC_OUT)

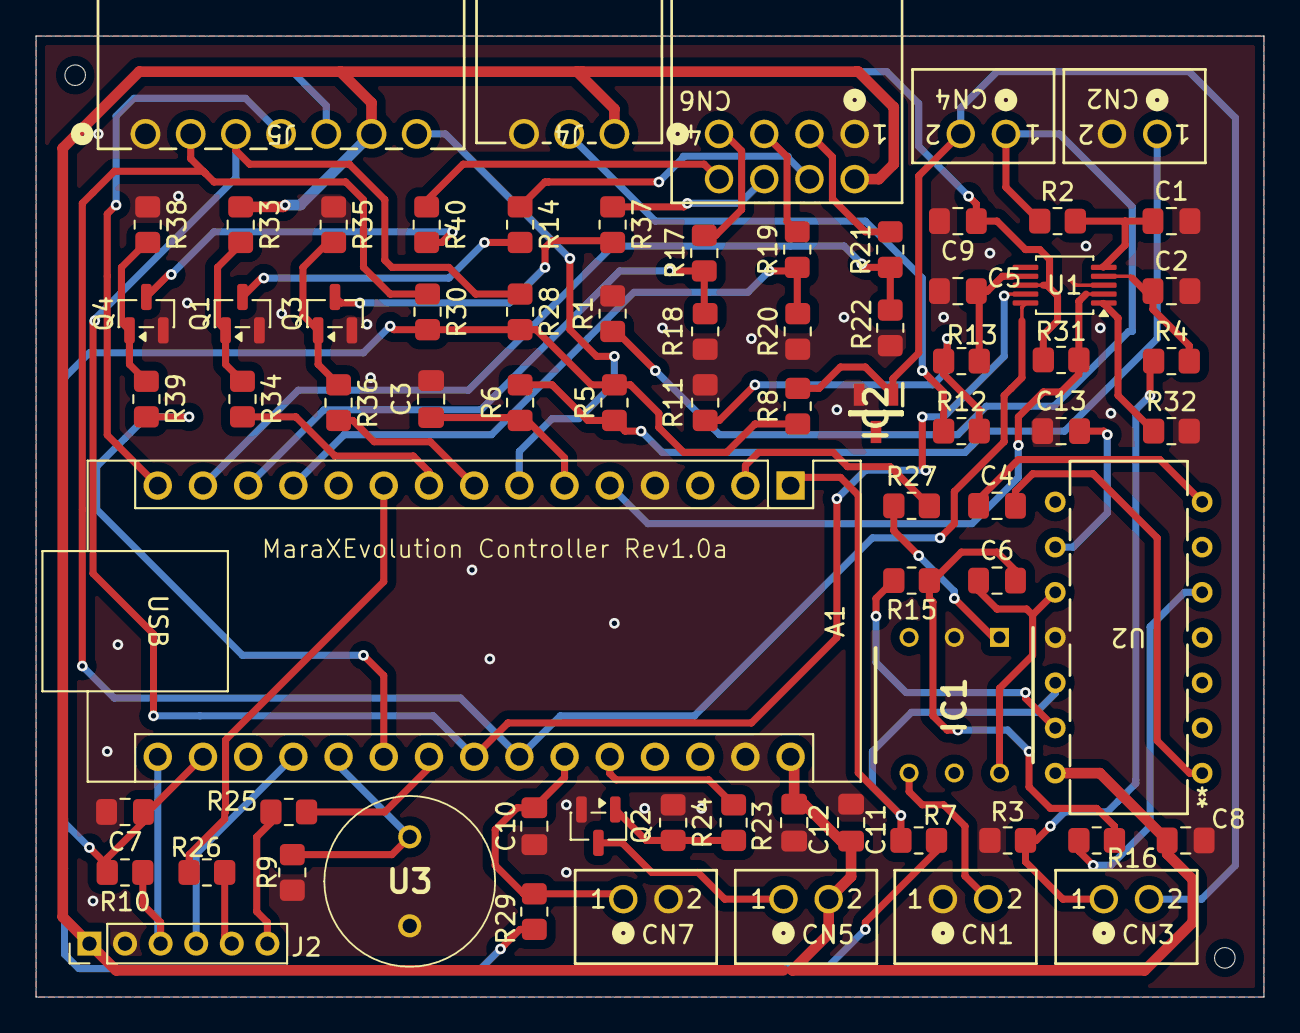
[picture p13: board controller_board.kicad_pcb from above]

Board: 2 copper layers, 69.0 x 54.0 mm, 73 parts (0 on the bottom side), 59 nets.

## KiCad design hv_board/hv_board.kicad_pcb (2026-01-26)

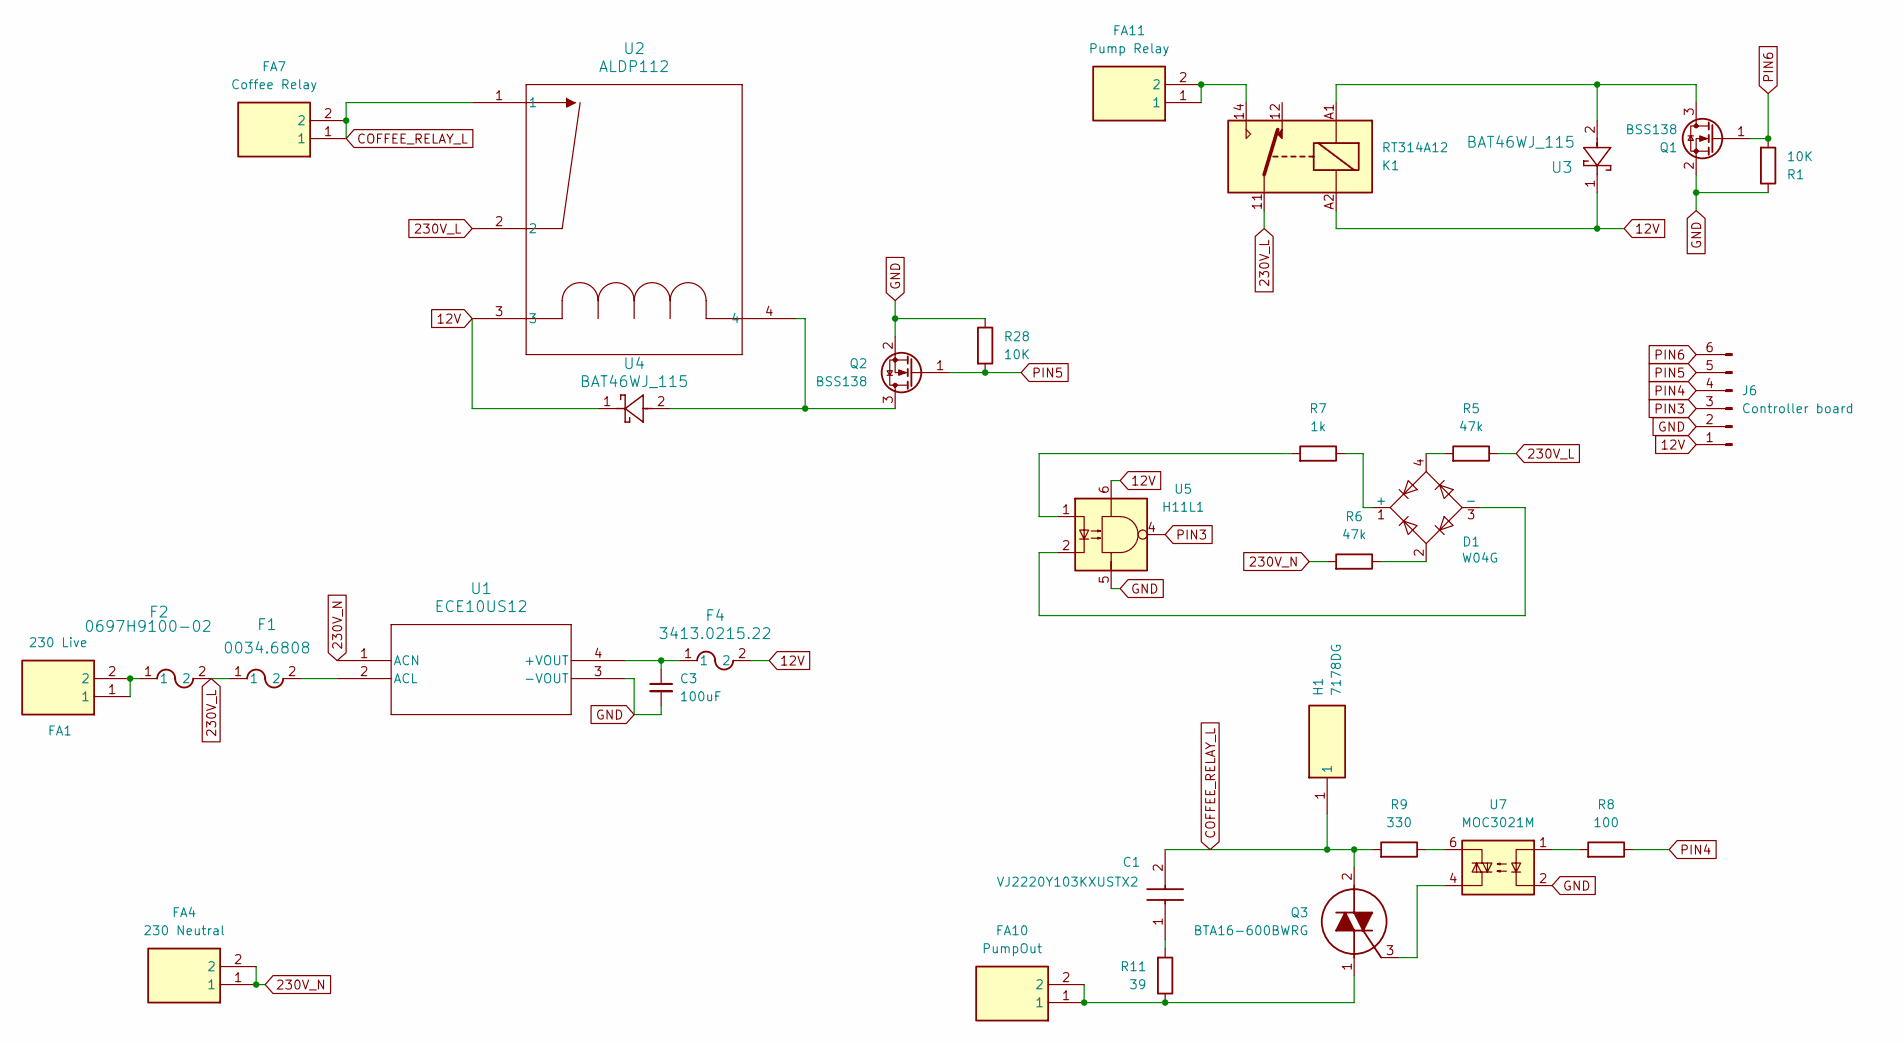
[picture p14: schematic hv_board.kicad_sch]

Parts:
C1: VJ2220Y103KXUSTX2; CAPC5651X218N; Mouser Part Number 77-VJ2220Y103KXUSTX2
C3: 100uF; CP_Radial_D6.3mm_P2.50mm
D1: W04G; Diode_Bridge_Round_D9.8mm
F1: 0034.6808; FUS_SCHURTER_0034_SCH
F2: 0697H9100-02; 0697_BEL
F4: 3413.0215.22; FUS1206_24N_SCH
FA1: 230 Live; 1606502; Manufacturer_Part_Number 160650-2; Mouser Part Number 571-160650-2
FA4: 230 Neutral; 1606502; Manufacturer_Part_Number 160650-2; Mouser Part Number 571-160650-2
FA7: Coffee Relay; 1606502; Manufacturer_Part_Number 160650-2; Mouser Part Number 571-160650-2
FA10: PumpOut; 1606502; Manufacturer_Part_Number 160650-2; Mouser Part Number 571-160650-2
FA11: Pump Relay; 1606502; Manufacturer_Part_Number 160650-2; Mouser Part Number 571-160650-2
H1: 7178DG; Mouser Part Number 532-7178DG
J6: Controller board; PinHeader_1x06_P2.00mm_Vertical
K1: RT314A12; Relay_SPDT_Schrack-RT1-16A-FormC_RM5mm
Q1, Q2: BSS138; SOT-23
Q3: BTA16-600BWRG; TO255P460X1020X2005-3P; Mouser Part Number 511-BTA16-600BW
R1, R28: 10K; R_0805_2012Metric_Pad1.20x1.40mm_HandSolder
R5, R6: 47k; R_2010_5025Metric_Pad1.40x2.65mm_HandSolder
R7: 1k; R_0805_2012Metric_Pad1.20x1.40mm_HandSolder
R8: 100; R_0805_2012Metric_Pad1.20x1.40mm_HandSolder
R9: 330; R_2010_5025Metric_Pad1.40x2.65mm_HandSolder
R11: 39; R_2010_5025Metric_Pad1.40x2.65mm_HandSolder
U1: ECE10US12; RELAY4_ECE10_XPR
U2: ALDP112; PAN_ALD_PAN
U3, U4: BAT46WJ_115; SC-90_SOD323F_NEX
U5: H11L1; H11L1_ISO
U7: MOC3021M; PDIP6_BX_ONS

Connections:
12V: F4.2, J6.1, K1.A2, U2.3, U3.1, U4.1, U5.6
230V_L: F1.1, F2.2, K1.11, R5.1, U2.2
230V_N: FA4.1, FA4.2, R6.2, U1.1 (ACN)
COFFEE_RELAY_L: C1.2, FA7.1, FA7.2, H1.1, Q3.2 (A2), R9.2, U2.1
GND: C3.2, J6.2, Q1.2 (S), Q2.2 (S), R1.1, R28.1, U1.3 (-VOUT), U5.5, U7.2
unnamed: C1.1, R11.2
unnamed: D1.1 (+), R7.1
unnamed: D1.3 (-), U5.2
unnamed: D1.2, R6.1
unnamed: D1.4, R5.2
unnamed: F2.1, FA1.1, FA1.2
unnamed: FA11.1, FA11.2, K1.14
unnamed: K1.A1, Q1.3 (D), U3.2
unnamed: Q2.3 (D), U2.4, U4.2
unnamed: FA10.1, FA10.2, Q3.1 (A1), R11.1
unnamed: Q3.3 (G), U7.4
unnamed: R7.2, U5.1
unnamed: R8.2, U7.1
unnamed: R9.1, U7.6
unnamed: C3.1, F4.1, U1.4 (+VOUT)
unnamed: F1.2, U1.2 (ACL)
PIN3: J6.3, U5.4
PIN4: J6.4, R8.1
PIN5: J6.5, Q2.1 (G), R28.2
PIN6: J6.6, Q1.1 (G), R1.2

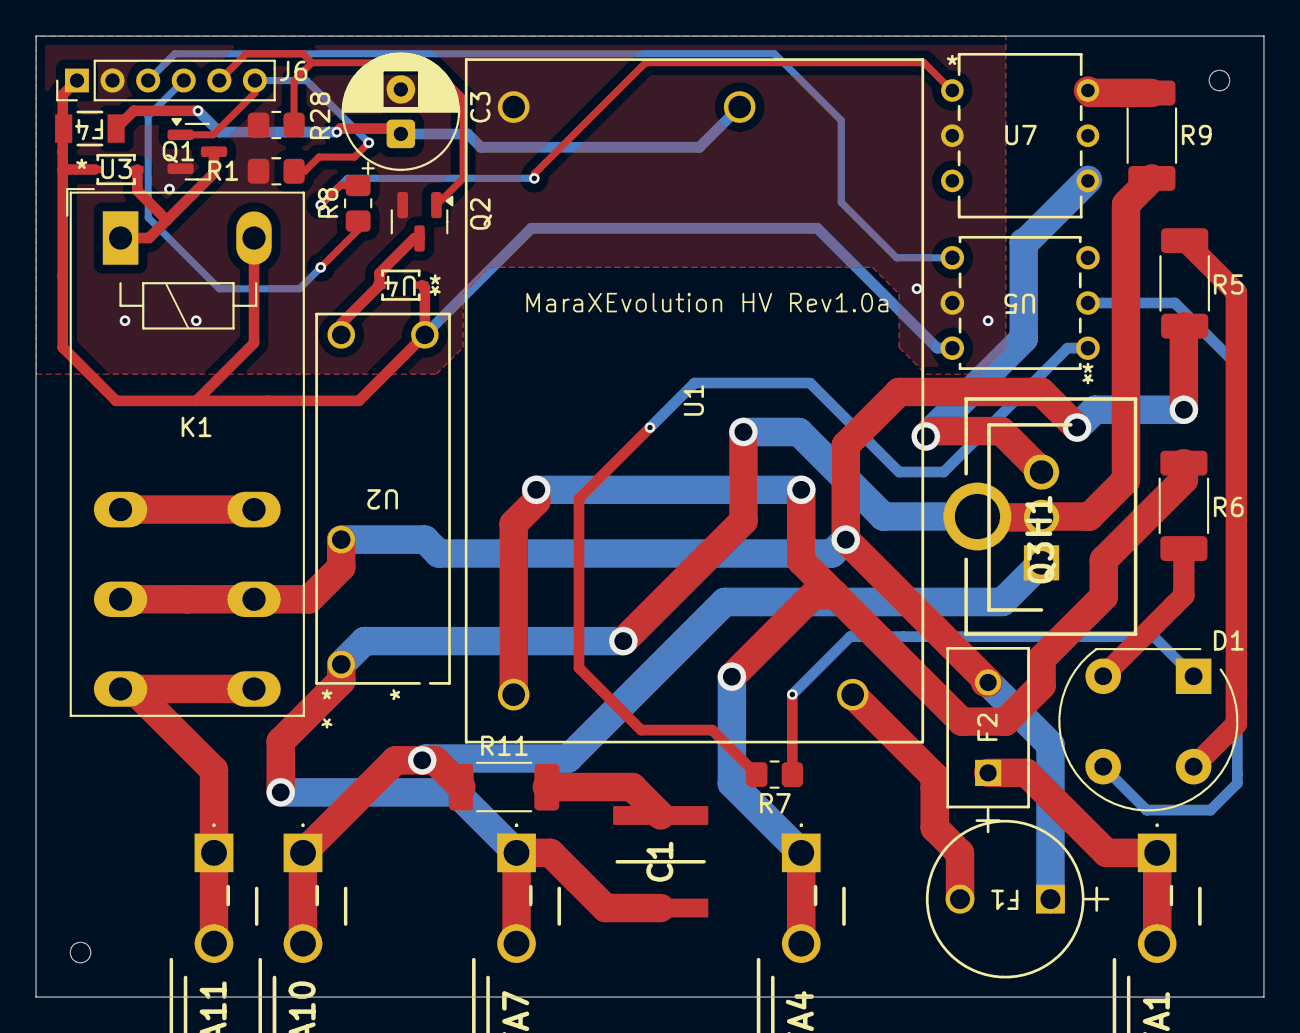
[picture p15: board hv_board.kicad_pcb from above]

Board: 2 copper layers, 69.0 x 54.0 mm, 31 parts (0 on the bottom side), 25 nets.

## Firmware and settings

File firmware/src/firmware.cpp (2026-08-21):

// =================================================================
// --- USER CONFIGURATION & DEFINES ---
// =================================================================
// #define HAS_PRESSURE_GAUGE
// #define HAS_SCALE
// #define HAS_SCREEN

// =================================================================
// --- LIBRARIES ---
// =================================================================
#include <Arduino.h>
#include <WiFi.h>
#include <ESPmDNS.h>
#include <WiFiUdp.h>
#include <ArduinoOTA.h>
#include <Wire.h>
#include <Adafruit_ADS1X15.h>
#include "PID_v1.h"
#include <AsyncMqttClient.h>
#include <Preferences.h>
#include <ArduinoJson.h>
#include <DNSServer.h>
#include <WebServer.h>
#include <WiFiManager.h>
#include <nvs_flash.h>
#ifdef HAS_SCREEN
#include <esp_now.h>
#endif
#include <esp_pm.h>
#include <esp_wifi.h>
#include <esp_wifi_types.h>
#ifdef HAS_SCALE
#include "SimpleKalmanFilter.h"
#endif
#ifdef HAS_PRESSURE_GAUGE
#include "dimmable_light.h"
#endif

// =================================================================
// --- HARDWARE PIN DEFINITIONS ---
// =================================================================
const int BOILER_LEVEL = D1;
const int WATER_DETECTOR = D3;
const int THREE_WAY_SWITCH1 = D9;
const int THREE_WAY_SWITCH2 = D11;
const int TWO_WAY_SWITCH = D10;
const int BREW_SWITCH = A6;
const int ENABLE_LM1830 = D0;
const int BUZZER = A1;
const int LEDMAIN = D6;
const int LEDHEATER = D8;
const int LEDWATER = D5;
const int PUMP_RELAY = A3;
const int COFFEE_RELAY = D7;
const int HEATER_SSR = A7;
const int ZERO_CROSS_PIN = D13; // green
const int PUMP_TRIAC_PIN = A2;  // yellow
const int ADS_SCLK_PIN = D4;    // scale
const int ADS_DOUT_PIN = D12;   // scale

// Analog input channels for ADS1115
const int BOILER_TEMP = 0;
const int HX_TEMP = 1;
const int PRESSURE = 3;

// Pin Arrays for setup loops
const int digitalOutputs[] = {ENABLE_LM1830, LEDMAIN, LEDHEATER, LEDWATER, PUMP_RELAY, COFFEE_RELAY, HEATER_SSR, BUZZER};
const int startupOutputPins[] = {ENABLE_LM1830, LEDHEATER, LEDWATER, PUMP_RELAY, COFFEE_RELAY, HEATER_SSR, BUZZER};
const int digitalInputs[] = {BOILER_LEVEL, WATER_DETECTOR, THREE_WAY_SWITCH1, THREE_WAY_SWITCH2, TWO_WAY_SWITCH, BREW_SWITCH};

// =================================================================
// --- PIN LOOKUP TABLE (FOR TELNET) ---
// =================================================================
struct PinLookup
{
  const char *name;
  int pin;
};

static const PinLookup pinMap[] = {
    {"boiler_level", BOILER_LEVEL},
    {"water_detector", WATER_DETECTOR},
    {"three_way_switch1", THREE_WAY_SWITCH1},
    {"three_way_switch2", THREE_WAY_SWITCH2},
    {"two_way_switch", TWO_WAY_SWITCH},
    {"brew_switch", BREW_SWITCH},
    {"enable_lm1830", ENABLE_LM1830},
    {"buzzer", BUZZER},
    {"ledmain", LEDMAIN},
    {"ledheater", LEDHEATER},
    {"ledwater", LEDWATER},
    {"pump_relay", PUMP_RELAY},
    {"coffee_relay", COFFEE_RELAY},
    {"heater_ssr", HEATER_SSR}};

static const int pinMapSize = sizeof(pinMap) / sizeof(pinMap[0]);

// =================================================================
// --- NETWORK & COMMUNICATION CONFIGURATION ---
// =================================================================

// --- MQTT Broker Configuration ---
char mqtt_server[40] = "";
int mqtt_port = 1883;
char mqtt_user[33] = "";
char mqtt_password[33] = "";
const char *mqtt_client_id = "MaraXV2CustomEspresso";

// --- MQTT Topics ---
// Status Topics
const char *mqtt_topic_state = "espresso/status/state";
const char *mqtt_topic_brew_mode = "espresso/status/brew_mode";
const char *mqtt_topic_steam_boost = "espresso/status/steam_boost";
const char *mqtt_topic_boiler_temp = "espresso/sensor/boiler_temp";
const char *mqtt_topic_hx_temp = "espresso/sensor/hx_temp";
#ifdef HAS_PRESSURE_GAUGE
const char *mqtt_topic_pressure = "espresso/sensor/pressure";
#endif
const char *mqtt_topic_heater = "espresso/sensor/heater";
const char *mqtt_topic_pump = "espresso/sensor/pump";
const char *mqtt_topic_lever = "espresso/sensor/lever";
const char *mqtt_topic_pidoutput = "espresso/sensor/pidoutput";
const char *mqtt_topic_pterm = "espresso/sensor/pterm";
const char *mqtt_topic_iterm = "espresso/sensor/iterm";
const char *mqtt_topic_dterm = "espresso/sensor/dterm";
#ifdef HAS_SCALE
const char *mqtt_topic_weight = "espresso/sensor/weight";
const char *mqtt_topic_flow_rate = "espresso/sensor/flow_rate";
#endif
const char *mqtt_topic_mqtt_server = "espresso/settings/status/mqtt_server";
const char *mqtt_topic_mqtt_port = "espresso/settings/status/mqtt_port";
const char *mqtt_topic_mqtt_user = "espresso/settings/status/mqtt_user";
const char *mqtt_topic_mqtt_pass = "espresso/settings/status/mqtt_pass";
// Settings Status Topics
const char *mqtt_topic_set_temp_brew = "espresso/settings/status/tempsetbrew";
const char *mqtt_topic_set_temp_steam = "espresso/settings/status/tempsetsteam";
const char *mqtt_topic_set_temp_steam_boost = "espresso/settings/status/tempsetsteamboost";
const char *mqtt_topic_set_kp_temperature = "espresso/settings/status/kp_temperature";
const char *mqtt_topic_set_ki_temperature = "espresso/settings/status/ki_temperature";
const char *mqtt_topic_set_kd_temperature = "espresso/settings/status/kd_temperature";
const char *mqtt_topic_set_profiling_mode = "espresso/settings/status/profiling_mode";
const char *mqtt_topic_set_profiling_source = "espresso/settings/status/profiling_source";
const char *mqtt_topic_set_profiling_target = "espresso/settings/status/profiling_target";
const char *mqtt_topic_profile_data = "espresso/settings/status/profile_data";
const char *mqtt_topic_profile_flat = "espresso/settings/status/profiling_flat_value";
const char *mqtt_topic_active_profile_id = "espresso/settings/status/active_profile_id";

const char *mqtt_topic_set_kp_pressure = "espresso/settings/status/kp_pressure";
const char *mqtt_topic_set_ki_pressure = "espresso/settings/status/ki_pressure";
const char *mqtt_topic_set_kd_pressure = "espresso/settings/status/kd_pressure";
const char *mqtt_topic_set_kp_flow = "espresso/settings/status/kp_flow";
const char *mqtt_topic_set_ki_flow = "espresso/settings/status/ki_flow";
const char *mqtt_topic_set_kd_flow = "espresso/settings/status/kd_flow";
#ifdef HAS_SCALE
// Kalman Filter Topics
const char *mqtt_topic_set_flow_kalman_me = "espresso/settings/status/flow_kalman_me";
const char *mqtt_topic_set_flow_kalman_e = "espresso/settings/status/flow_kalman_e";
const char *mqtt_topic_set_flow_kalman_q = "espresso/settings/status/flow_kalman_q";
const char *mqtt_topic_set_weight_kalman_me = "espresso/settings/status/weight_kalman_me";
const char *mqtt_topic_set_weight_kalman_e = "espresso/settings/status/weight_kalman_e";
const char *mqtt_topic_set_weight_kalman_q = "espresso/settings/status/weight_kalman_q";
#endif
// Settings Control Topic
const char *mqtt_topic_set = "espresso/settings/set";

// --- OTA (Over-the-Air Updates) ---
const char *ota_hostname = "esp32-arduino";
const char *ota_password = "1234";

// --- Global Connection State ---
bool isOnline = false;
WiFiManager wm;

// =================================================================
// --- SYSTEM & LIBRARY OBJECTS ---
// =================================================================
WiFiServer telnetServer(23);
WiFiClient telnetClient;
AsyncMqttClient mqttClient;
Preferences preferences;
Adafruit_ADS1115 ads;
#ifdef HAS_PRESSURE_GAUGE
DimmableLight pumpDimmer(PUMP_TRIAC_PIN);
#endif
#ifdef HAS_SCREEN
typedef struct struct_message
{
  char payload[250];
} struct_message;
typedef struct struct_pairing
{
  uint8_t id;
  uint8_t macAddr[6];
  uint8_t channel;
  char identifier[10];
} struct_pairing;
const char *espIdentifier = "espresso";
struct_message myData;
struct_pairing pairingData;
uint8_t screenMacAddress[6];
bool isScreenPaired = false;
int myChannel = 0;
esp_now_peer_info_t peerInfo;
#define PAIR_REQUEST 1
#define PAIR_RESPONSE 2

// --- ESP-NOW Buffering ---
const int MAX_ESPNOW_BUFFER = 250;
char espNowMessageBuffer[MAX_ESPNOW_BUFFER] = {0}; // Initialize with nulls
int espNowCurrentLength = 0;
const unsigned long ESP_NOW_SEND_INTERVAL_MS = 250;
static unsigned long lastEspNowSendTime = 0;
volatile bool espNowBusy = false;
volatile bool pendingScreenSync = false;
#endif

#ifdef HAS_SCALE
// =================================================================
// --- SCALE (ADS1232) CONFIGURATION & GLOBALS ---
// =================================================================
// --- I2C Configuration ---
const int PCF8574_ADDRESS = 0x38;
const int SCALE_CHANNEL = 2;

// --- PCF8574 Pin Mapping ---
const byte PCF_PDWN_BIT = 7;
const byte PCF_SPEED_BIT = 4;
const byte PCF_GAIN0_BIT = 6;
const byte PCF_GAIN1_BIT = 5;
const byte PCF_TEMP_BIT = 0;
const byte PCF_A0_BIT = 2;

// --- Calibration Values ---
long COMBINED_OFFSET = 0;
float COMBINED_SCALE = 1.0;

// --- Global Variables ---
volatile boolean newDataReady = false;
portMUX_TYPE scaleMux = portMUX_INITIALIZER_UNLOCKED;
byte pcfState = 0;
long loadCellValue = 0;
float currentWeight = 0.0;
float calibrationWeight = 0.0;
static float lastRawWeight = 0.0;
static float pendingWeight = 0.0;
static bool isWeightPending = false;
static bool isFirstScaleReading = true;
const float SPIKE_THRESHOLD_G = 25.0;
const int SCALE_BLANKING_PERIOD_MS = 500;

// --- Kalman Filter for Flow Rate ---
float flowKalmanMe = 30.0;
float flowKalmanE = 2.0;
float flowKalmanQ = 0.1;
SimpleKalmanFilter flowKalmanFilter(flowKalmanMe, flowKalmanE, flowKalmanQ);
float weightKalmanMe = 8.0;
float weightKalmanE = 2.0;
float weightKalmanQ = 0.1;
SimpleKalmanFilter weightKalmanFilter(weightKalmanMe, weightKalmanE, weightKalmanQ);

// --- Flow Rate Calculation ---
float flowRate = 0.0f;
float previousWeightForFlowCalc = 0.0f;
unsigned long previousTimeForFlowCalc = 0;
#endif

// =================================================================
// --- FLOW PROFILING ---
// =================================================================

#define MAX_PROFILE_STEPS 16
#define MAX_PROFILES 20

struct ProfileStep
{
  float trigger;  // X-axis value (Time in seconds OR Weight in grams)
  float setpoint; // Y-axis value (Pressure in bar OR Flow in g/s)
};

struct __attribute__((packed)) EspressoProfile
{
  uint8_t id;
  char name[65];
  bool isStepped;
  bool isTargetWeight; // false = time, true = weight
  bool isSourceFlow;   // false = pressure, true = flow
  uint8_t numSteps;
  ProfileStep steps[MAX_PROFILE_STEPS];
  int8_t nextProfileId; // Profile ID to run next (-1 for none)
};

EspressoProfile profiles[MAX_PROFILES];

EspressoProfile *currentProfile = &profiles[0];
uint8_t currentProfileIndex = 0;

int numProfilePoints = 0;

// --- Profiling State Tracking ---
int currentProfileStepIndex = 0;
float currentStepStartX = 0.0f;
float prevStepTargetY = 0.0f;
unsigned long shotStartTime = 0;
unsigned long profileStartTime = 0;
float profileStartWeight = 0.0f;
EspressoProfile *executingProfile = &profiles[0];

// =================================================================
// --- STATE MACHINE ---
// =================================================================
// --- State Definitions ---
enum MachineState
{
  WATER_EMPTY,
  BOILER_EMPTY,
  HEATING,
  BREWING,
  STANDBY,
  IDLE,
  CLEANING_START,
  CLEANING_PUMPING,
  CLEANING_PAUSE,
  STEAM_BOOST,
  COOLING_FLUSH,
  ERROR,
  DEBUG,
  INIT,
  CALIBRATION_EMPTY,
  CALIBRATION_TEST_WEIGHT
};

// --- State Control Variables ---
MachineState currentState;
MachineState calibrationReturnState = HEATING;
char lastError[128] = "";
unsigned long lastStateTransitionTime = 0;
unsigned long idleEntryTime = 0;
unsigned long flushStartTime = 0;
unsigned long boilerFullTimestamp = 0;
unsigned long steamBoostEntryTime = 0;
long coolingFlushEndTime = 0;
unsigned long programmaticFlushEndTime = 0;

// Timer to track post-shot dripping
unsigned long shotEndTime = 0;
const unsigned long SHOT_POST_DRIP_DURATION_MS = 3000;

// --- Input State Variables ---
bool waterLevelTripped = false;
volatile bool isBoilerEmpty = false;
bool brewLeverLifted = false;
bool threeWaySwitch1High = false;
bool threeWaySwitch2High = false;
bool leverLiftedInStandby = false;
bool isBoilerPinHigh = false;
unsigned long lastBoilerCheckTime = 0;
unsigned long lastLeverChangedTime = 0;
unsigned long lastWaterLevelChangedTime = 0;
const unsigned long debounceDelay = 100;

// --- Override Flags ---
bool ignoreBrewSwitch = false;
bool ignoreTempSwitch = false;
bool firstMqttConnection = true;

// =================================================================
// --- OPERATIONAL PARAMETERS & SETTINGS ---
// =================================================================
// --- Brewing & Steaming Temperatures ---
char brewMode[7];
bool enableSteamBoost = true;
float tempSetBrew = 94.0;
float tempSetSteamBoost = 124.0;
float tempSetSteam = 136.0;
float tempSetSteamHeating = 28;
double calculatedBoilerTemp = 0.0;
const double FF_ONLY_THRESHOLD = 4.0;
const double BOILER_WAY_TOO_HOT = 10.0;
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
void loop()
{
  unsigned long nowTime = millis();

  wm.process();

  if (WiFi.status() == WL_CONNECTED)
  {
    if (!isOnline)
    {
      printlnToAll("WiFi Connected!");
      isOnline = true;
      startNetworkServices();
    }
  }
  else
  {
    if (isOnline)
    {
      printlnToAll("WiFi Lost!");
      isOnline = false;
    }
  }

  if (isBeeping && nowTime >= beepStopTime)
  {
    digitalWrite(BUZZER, LOW);
    isBeeping = false;
  }
  if (isOnline)
  {
    ArduinoOTA.handle();
  }
#ifdef HAS_SCREEN
  if (nowTime - lastEspNowSendTime > ESP_NOW_SEND_INTERVAL_MS)
  {
    sendEspNowBuffer();
    lastEspNowSendTime = nowTime;
  }
  if (pendingScreenSync)
  {
    pendingScreenSync = false;
    printlnToAll("Syncing all settings and state to new screen.");
    publishSettings();
    publishState();
  }
#endif

  handleTelnet();
  pollDigitalInputs();
  updateSensorReadings();
#ifdef HAS_SCALE
  handleScale();
#endif
  periodicBoilerLevelCheck();
  updateBrewMode();
  updateTempSwitch();

  bool errorState = false;
  if (currentState != DEBUG)
  {
    if (checkCriticalSensorFailure())
    {
      transitionToState(ERROR);
      errorState = true;
    }
    else if (waterLevelTripped)
    {
      // --- NEW GRACE PERIOD LOGIC ---
      if (currentState == BREWING)
      {
        if (!lowWaterGracePeriodActive)
        {
          lowWaterGracePeriodActive = true;
          lowWaterGracePeriodStartTime = nowTime;
          printlnToAll("Low water detected mid-shot! 30s grace period started.");
        }
        else if (nowTime - lowWaterGracePeriodStartTime >= LOW_WATER_GRACE_PERIOD_MS)
        {
          printlnToAll("Grace period expired! Aborting shot to protect pump.");
          transitionToState(WATER_EMPTY);
          errorState = true;
        }
      }
      else
      {
        if (currentState != WATER_EMPTY)
        {
          if (currentState == CLEANING_START || currentState == CLEANING_PUMPING || currentState == CLEANING_PAUSE)
          {
            cleaningStateToResume = currentState;
            printlnToAll("Water empty during cleaning. Pausing cycle...");
          }
          else
          {
            cleaningStateToResume = IDLE;
          }
        }
        transitionToState(WATER_EMPTY);
        errorState = true;
      }
    }
    else if (isBoilerEmpty && !waterLevelTripped)
    {
      transitionToState(BOILER_EMPTY);
      errorState = true;
    }
  }

  switch (currentState)
  {
  case INIT:
    transitionToState(HEATING);
    break;
  case ERROR:
    errorBuzzer();
    ledError();
    if (!checkCriticalSensorFailure() && !errorState)
    {
      digitalWrite(BUZZER, LOW);
      transitionToState(HEATING);
      break;
    }
    break;
  case WATER_EMPTY:
    waterEmptyBuzzer();
    ledWaterEmpty();
    if (!errorState)
    {
      digitalWrite(BUZZER, LOW);
      if (cleaningStateToResume != IDLE)
      {
        printlnToAll("Water refilled. Resuming cleaning cycle.");
        transitionToState(cleaningStateToResume);
        cleaningStateToResume = IDLE;
      }
      else
      {
        transitionToState(HEATING);
      }
      break;
    }
    break;
  case BOILER_EMPTY:
  {
    if (brewLeverLifted)
    {
      setBoilerFillValve(false);
      setPump(false);
      break;
    }
    if (!brewLeverLifted)
    {
      setBoilerFillValve(true);
      setPump(true);
    }
    bool waterDetected = readPin(BOILER_LEVEL);

    if (waterDetected)
    {
      if (boilerFullTimestamp == 0)
      {
        boilerFullTimestamp = nowTime;
      }
      if (!errorState && (nowTime - boilerFullTimestamp >= BOILER_OVERFILL_DURATION_MS))
      {
        transitionToState(HEATING);
      }
    }
    else
    {
      boilerFullTimestamp = 0;
    }
    break;
  }
  case HEATING:
  {
    runHeaterPID();
    ledHeating();
    if (brewLeverLifted)
    {
      if (programmaticFlushEndTime > 0)
      {
        programmaticFlushEndTime = 0;
        printlnToAll("Programmatic flush cancelled by lever.");
      }
      transitionToState(BREWING);
      break;
    }
    bool flushRunning = isProgrammaticFlushActive();
    if (flushRunning)
    {
      setPumpPower(100);
      setBoilerFillValve(false);
      setPump(true);
      break;
    }
    setBoilerFillValve(false);
    setPump(false);
    if ((nowTime - lastStateTransitionTime > 10000) && isStable())
    {
      bool heatingModeCoffee = strcmp(brewMode, "STEAM");

      if (heatingModeCoffee)
      {
        printlnToAll("Temperature stable -> IDLE.");
        transitionToState(IDLE);
      }
      else
      {
        transitionToState(COOLING_FLUSH);
      }
      break;
    }
    break;
  }
  case COOLING_FLUSH:
  {
    if (nowTime - flushStartTime >= COOLING_FLUSH_DURATION_MS)
    {
      setBoilerFillValve(false);
      setPump(false);
      transitionToState(IDLE);
      coolingFlushEndTime = nowTime;
      break;
    }
    break;
  }
  case IDLE:
  {
    runHeaterPID();
    ledIdle();
    bool heatingModeCoffee = strcmp(brewMode, "STEAM");
    if (heatingModeCoffee && abs(pidInput - pidSetpoint) > TEMP_STABILITY_TOLERANCE && nowTime - coolingFlushEndTime > 60000)
    {
      printlnToAll("Temperature unstable. Returning to HEATING state.");
      transitionToState(HEATING);
      break;
    }
    if (brewLeverLifted)
    {
      if (programmaticFlushEndTime > 0)
      {
        programmaticFlushEndTime = 0;
        printlnToAll("Programmatic flush cancelled by lever.");
      }
      transitionToState(BREWING);
      break;
    }
    bool flushRunning = isProgrammaticFlushActive();
    if (flushRunning)
    {
      setPumpPower(100);
      setBoilerFillValve(false);
      setPump(true);
      break;
    }
    setBoilerFillValve(false);
    setPump(false);
    if (standbyTimoutReached())
    {
      transitionToState(STANDBY);
      break;
    }
    if (!heatingModeCoffee)
    {
      if (nowTime - idleEntryTime >= PERIODIC_FLUSH_INTERVAL_MS)
      {
        printlnToAll("Periodic flush triggered");
        transitionToState(COOLING_FLUSH);
        break;
      }
    }
    break;
  }
  case BREWING:
    runHeaterPID();
    ledBrew();
    runPumpProfile();

    if (!brewLeverLifted)
    {
      if (lowWaterGracePeriodActive || waterLevelTripped)
      {
        transitionToState(WATER_EMPTY);
      }
      else if (enableSteamBoost)
      {
        transitionToState(STEAM_BOOST);
      }
      else
      {
        transitionToState(HEATING);
      }
    }
    break;
  case STEAM_BOOST:
  {
    runHeaterPID();
    if (nowTime - steamBoostEntryTime >= STEAM_BOOST_DURATION_MS)
    {
      transitionToState(HEATING);
    }
    break;
  }
  case STANDBY:
    ledStandby();
    if (brewLeverLifted)
    {
      leverLiftedInStandby = true;
    }

    if (leverLiftedInStandby && !brewLeverLifted)
    {
      transitionToState(HEATING);
    }
    break;
  case CLEANING_START:
  {
    runHeaterPID();
    ledIdle();

    if (brewLeverLifted)
    {
      printlnToAll("Cleaning cycle 1/10: Lever lifted, starting pump.");
      cleaningPumpStartTime = nowTime;
      cleaningBeepState = 0;
      transitionToState(CLEANING_PUMPING);
    }
    break;
  }
  case CLEANING_PUMPING:
  {
    runHeaterPID();
    ledIdle();

    const unsigned long PUMP_DURATION_MS = 10000;
    const int BEEP_DURATION_MS = 150;
    const int BEEP_PAUSE_MS = 150;

    if (cleaningBeepState == 0 && (nowTime - cleaningPumpStartTime >= PUMP_DURATION_MS))
    {
      cleaningBeepState = 1;
      cleaningBeepTimer = nowTime;
      if (BUZZER_ENABLE)
        digitalWrite(BUZZER, HIGH);
    }

    if (cleaningBeepState == 1)
    {
      if (nowTime - cleaningBeepTimer >= BEEP_DURATION_MS)
      {
        digitalWrite(BUZZER, LOW);
        cleaningBeepTimer = nowTime;
        if (cleaningRepetitionCounter == 4)
        {
          cleaningBeepState = 2;
        }
        else
        {
          cleaningBeepState = 4;
        }
      }
    }
    else if (cleaningBeepState == 2)
    {
      if (nowTime - cleaningBeepTimer >= BEEP_PAUSE_MS)
      {
        if (BUZZER_ENABLE)
          digitalWrite(BUZZER, HIGH);
        cleaningBeepTimer = nowTime;
        cleaningBeepState = 3;
      }
    }
    else if (cleaningBeepState == 3)
    {
      if (nowTime - cleaningBeepTimer >= BEEP_DURATION_MS)
      {
        digitalWrite(BUZZER, LOW);
        cleaningBeepState = 4;
      }
    }

    if (!brewLeverLifted)
    {
      setPump(false);
      digitalWrite(BUZZER, LOW);
      cleaningRepetitionCounter++;

      if (cleaningRepetitionCounter >= TOTAL_CLEANING_REPETITIONS)
      {
        printlnToAll("Cleaning cycle finished.");
        cleaningRepetitionCounter = 0;
        cleaningStateToResume = IDLE;
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

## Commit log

2025-12-25 Revise README for MaraX Evolution project
    Updated README to provide detailed project information, features, repository structure, assembly instructions, firmware compilation steps, and dependencies for the MaraX Evolution main controller.
2025-12-27 Add parts list and component details to README
    Added a parts list section with details on components and recommendations for resistor tolerances.
2025-12-27 New bom
    [BOM-controller_board.csv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]
2025-12-30 New gerber files
    [BOM-controller_board.csv, BOM-hv_board.csv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]
2025-12-30 Adds parts list for controller board to README
2025-12-30 Adds part list for HV board
2026-01-03 allow cleaning when in heating and warm enough
2026-01-26 Many fixes
    [controller_board-CuBottom.gbr, controller_board-CuTop.gbr, controller_board-EdgeCuts.gbr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]
2026-02-02 Enhance assembly instructions with images
    Added multiple images to assembly instructions.
2026-02-02 Update ASSEMBLY.md with assembly instructions and images
    Added detailed assembly instructions and images for the controller and HV boards, including key assembly notes and wiring connections.
2026-02-02 Revise README features and assembly instructions
    Updated feature descriptions for clarity and added details about optional upgrades and integration.
2026-02-02 Add link to MaraX Evolution Scale in README
    Updated README to include link to MaraX Evolution Scale for flow profiling.
2026-02-06 Fix description of real shot with custom Controller
    Updated the description of the real shot with the custom Controller to reflect the correct weight and behavior of the valve.
2026-02-08 Set pump power to 100 for flushing and cleaning
2026-02-13 Prevent erroneous shutdown if scale reads negative values
    [firmware.cpp]
2026-02-13 We go to heating after brewing
2026-02-13 Revert "We go to heating after brewing"
    This reverts commit a1cfc95fdf79d9c06c25716c0c21d30a51324217.
    [firmware.cpp]
2026-02-14 Wait a bit when entering heating state to go to idle
2026-05-11 the callback should do as little as possible. prevents out of memory errors in espnow
    [firmware.cpp]
2026-08-21 prevent error after Boiler Fill
    [firmware.cpp]

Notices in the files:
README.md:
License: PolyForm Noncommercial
